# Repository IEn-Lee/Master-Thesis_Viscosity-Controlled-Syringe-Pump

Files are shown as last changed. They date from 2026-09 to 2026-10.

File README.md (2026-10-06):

# Viscosity-Controlled Syringe Pump for Precise Filling of a Urological Implant with High-Viscosity Oils

**Master's Thesis — I-En Lee**  
M.Sc. Computational Engineering  
Friedrich-Alexander-Universität Erlangen-Nürnberg (FAU)  
Institute for Factory Automation and Production Systems (FAPS)  
2026

**Thesis grade: 1.0 (highest possible grade in the German grading system)**  
**Recognition: Outstanding Master's Thesis** — [View certificate](https://github.com/IEn-Lee/Master-Thesis_Viscosity-Controlled-Syringe-Pump/blob/main/Certificate%20Outstanding%20Master's%20Thesis_Lee.pdf)<br>
**Full master's thesis:** The complete thesis is available as a PDF in this repository — [Full master's thesis](https://github.com/IEn-Lee/Master-Thesis_Viscosity-Controlled-Syringe-Pump/blob/main/Master_s%20Thesis.pdf). <br>
*(If GitHub fails to display the PDF preview, please download the file and open it locally)* <br>
<br>
> **RheoPilot | James Dyson Award 2026**  
> **[Explore the RheoPilot project on the James Dyson Award website](https://www.jamesdysonaward.org/en-US/2026/project/rheopilot)**

---

## Overview

This master's thesis developed **RheoPilot**, a **viscosity-controlled syringe pump for precise filling of a urological implant with high-viscosity oils**. The platform combines physical modeling, mechanical design, embedded control, sensor–actuator integration, a touchscreen interface, and experimental calibration in a working laboratory prototype.

The investigated fluids spanned approximately **1–60,000 mPa·s**, from water to high-viscosity silicone oils. The system was developed around **B. Braun Injekt Luer Lock Solo 2 mL syringes** and a narrow cannula, with a validation target of **1 mL delivery within ±1% volumetric deviation** under defined laboratory conditions.

<p align="center">
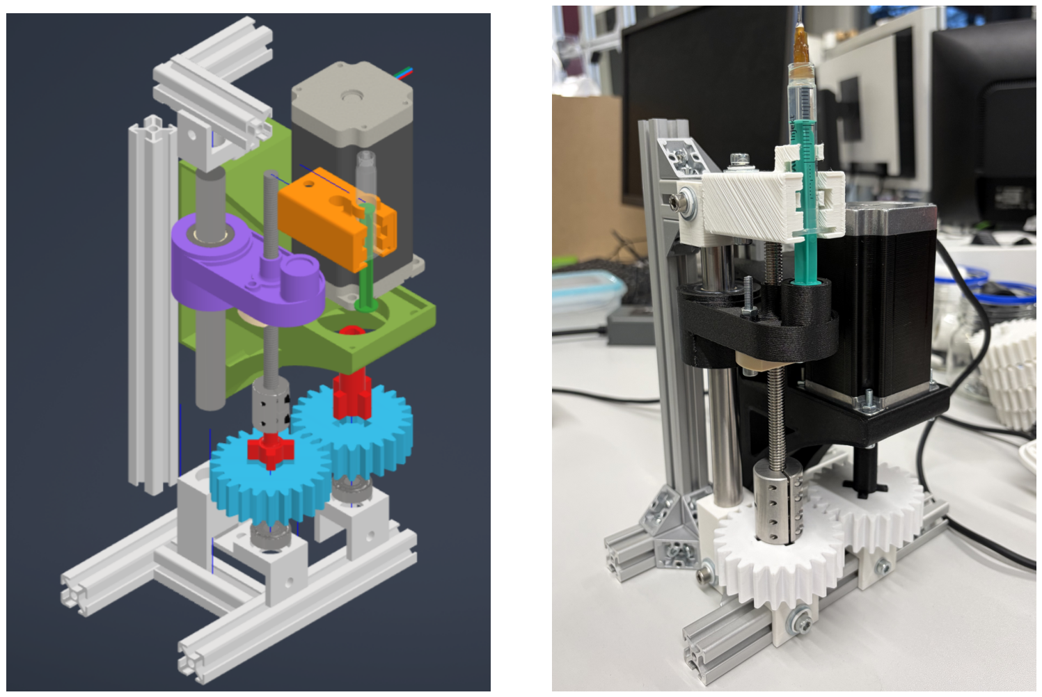
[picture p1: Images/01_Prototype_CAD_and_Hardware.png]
CAD installation reference beside the assembled syringe-pump prototype
  
</p>

*Figure 1. From CAD to a test-ready prototype. Left: installation reference. Right: the assembled syringe pump used for experimental evaluation. Source: original thesis Figure 39.*

**Key results**

- **Calibrated conditions:** maximum absolute volumetric deviation of **0.62%** across the reported trials at 1, 5,000, 30,000, and 60,000 mPa·s.
- **Intermediate validation:** at a nominal **40,000 mPa·s**, which was not a calibration point, **all five trials met the ±1% tolerance** using interpolated parameters without additional manual retuning.
- **Validation accuracy:** maximum absolute deviation of **0.93%** and mean absolute deviation of **0.72%** at that intermediate condition.
- **Post-extrusion handling:** retracting the plunger-contact interface enabled a standardized **3-minute post-release waiting interval** for the oil-based tests.

## Why This Research Was Needed

RheoPilot originated from a specific medical-device research problem: filling an internal component of an intraurethral implant with high-viscosity oil through a narrow cannula. This task requires a combination of accurate small-volume delivery, repeatable syringe positioning, manageable mechanical loading, and a practical laboratory workflow.

**Accurate plunger positioning alone does not guarantee accurate delivery at the outlet.** Under high-viscosity loading, syringe compliance, friction, structural deformation, and delayed outflow can change the relationship between commanded motion and delivered volume. In the thesis experiments, the uncompensated setting produced a mean absolute volumetric deviation of **30.31% at 60,000 mPa·s**, despite relatively consistent repeated trials. This made application-specific compensation necessary.

The equipment-selection challenge was to combine syringe-based operation with viscosity-dependent process planning and experimental flexibility. The thesis identified the following gap between existing approaches and the intended filling workflow:

| Approach considered in the thesis | Relevant capability | Additional need for this application |
|---|---|---|
| Conventional syringe pumps | Programmable plunger motion using syringe geometry, volume, and flow settings. | Compensation for the specific syringe–cannula system under high-viscosity loading, including delayed release. |
| Industrial viscous-material dispensers | Specialized metering of viscous materials. | Integration with the specified disposable 2 mL syringe and small-cannula implant-filling procedure. |
| Manual or semi-automated filling | Flexible preparation and operator intervention. | More reproducible actuation and post-extrusion handling, with traceable process settings. |

*This comparison summarizes the application-specific assessment in thesis Section 3.2 and Table 1; it is not an exhaustive benchmark of all commercial products.*

The resulting research objective was to develop an integrated **actuator–structure–fluid platform** that connects volume and viscosity inputs to motion planning, calibrated compensation, operator guidance, and quantitative validation.

### Why a Small Outlet Matters

<p align="center">
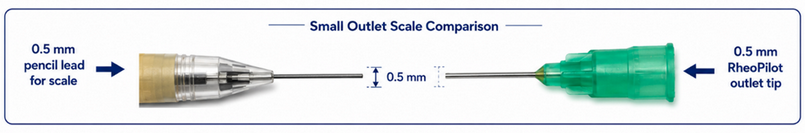
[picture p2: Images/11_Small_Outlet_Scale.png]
Visual scale comparison between a 0.5 mm mechanical-pencil lead and the RheoPilot cannula outlet
  
</p>

*Small-outlet scale comparison. The approximately 0.5 mm outlet scale is illustrated alongside a mechanical-pencil lead. This is a visual scale reference rather than a dimensional measurement.*

<p align="center">
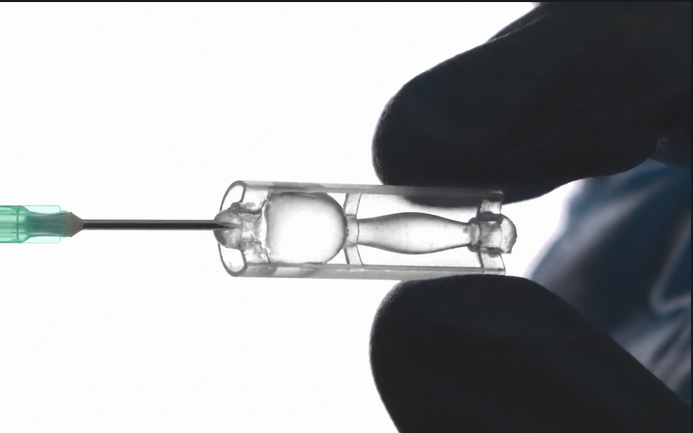
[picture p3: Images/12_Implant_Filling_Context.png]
Cannula positioned at the filling interface of a small transparent implant component held between gloved fingers
  
</p>

*Application context: cannula-based access to a small implant component. Image provided by the author; UroPro image credit: Alexander Preis, FAU FAPS.*

Small components can offer only a restricted filling interface. A narrow cannula provides localized access, but it also increases the resistance encountered by the fluid. Increasing the outlet size may therefore be incompatible with the component geometry or the required filling procedure.

For the idealized flow model used in this thesis, pressure loss scales with the inverse fourth power of the cannula radius. **Halving the radius increases the predicted pressure demand sixteenfold at the same viscosity, cannula length, and flow rate.** This makes a small outlet an important process constraint rather than merely a geometric detail.

RheoPilot addresses this constraint by relating viscosity and flow-path geometry to motion planning, then applying calibrated compensation for the actual syringe–cannula system. The objective is to deliver a defined volume through the required access point while accounting for mechanical loading and delayed material response.

## What Makes RheoPilot Different

**RheoPilot combines viscosity-dependent compensation with a compact, modular, standalone syringe-based workflow.** Its distinguishing feature is the combination of functions around the investigated filling task.

| Design feature | Practical value |
|---|---|
| **Viscosity-dependent motion planning and compensation** | Converts the filling task into motion settings that account for modeled loading and experimentally observed delivery deviations. |
| **Disposable-syringe compatibility** | Integrates the specified 2 mL syringe and Luer Lock cannula into a repeatable filling setup. |
| **Guided standalone operation** | Routine operation starts from target volume and viscosity; the embedded controller handles calculations, interface guidance, and motor commands on the device. |
| **Modular, fabrication-oriented construction** | Standard components and replaceable printed parts support assembly, modification, and iterative development. |
| **Advanced configuration access** | Exposes relevant setup parameters for research, while routine users interact with a simpler interface. |
| **Defined post-extrusion release** | Includes contact-element retraction and a standardized waiting step to address the delayed response of high-viscosity oils. |

The [RheoPilot project page on the James Dyson Award website](https://www.jamesdysonaward.org/en-US/2026/project/rheopilot) estimates **prototype parts costs of approximately €300–450**. This is a parts estimate, not a commercial selling price or a like-for-like comparison with a complete supported dispensing system.

The design supports adaptation of the syringe holder and outlet arrangement. **Each changed configuration would require appropriate calibration and validation**; the performance results below apply to the tested setup.

Figures 1, 4, and 5 show the physical implementation and modular interfaces; Figures 7–9 illustrate guided operation; Figure 10 and the validation tables explain the compensation strategy and measured results.

## My Contributions

- Developed a fluid-mechanical model and used Python for numerical evaluation of viscosity-dependent operating constraints.
- Designed the syringe fixation, plunger-contact interface, guidance, actuator mounting, and transmission interfaces in CAD.
- Applied **DFM and DfAM considerations**, including assembly clearances, printed-part tolerances, modular interfaces, and replaceable components.
- Integrated stepper-motor actuation, motor-driver electronics, electrical monitoring, embedded C/C++ software, and a touchscreen interface.
- Implemented **model-based open-loop compensation** using calibrated motion parameters and monotonic interpolation.
- Fabricated and assembled the prototype, conducted gravimetric experiments, and evaluated an intermediate condition excluded from calibration.

## 1. System Architecture and Integration

<p align="center">
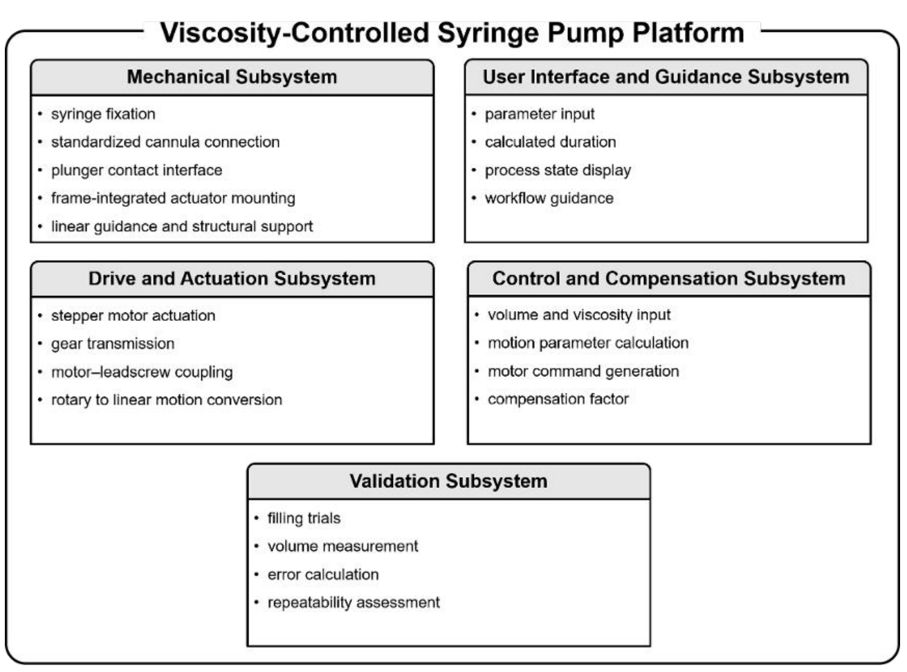
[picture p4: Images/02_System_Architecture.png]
Five functional subsystems: mechanics, drive and actuation, control and compensation, user interface and guidance, and validation
  
</p>

*Figure 2. Functional decomposition of the syringe-pump platform. Source: original thesis Figure 16.*

The architecture connects five engineering functions:

| Subsystem | Role in the filling process |
|---|---|
| Mechanical structure | Positions the syringe, supports the actuator, and guides the moving plunger-contact element. |
| Drive and actuation | Transfers motor rotation through the transmission and leadscrew into linear plunger displacement. |
| Control and compensation | Converts target volume and viscosity into executable, compensated motion commands. |
| User interface and guidance | Supports parameter entry, confirmation, process monitoring, and operator guidance. |
| Validation | Measures delivered volume and evaluates accuracy and repeatability under documented conditions. |

This structure made **system integration** central to the project: the model, hardware, firmware, interface, and measurement workflow had to operate consistently together.

## 2. Fluid-Mechanical Modeling and Motion Planning

<p align="center">
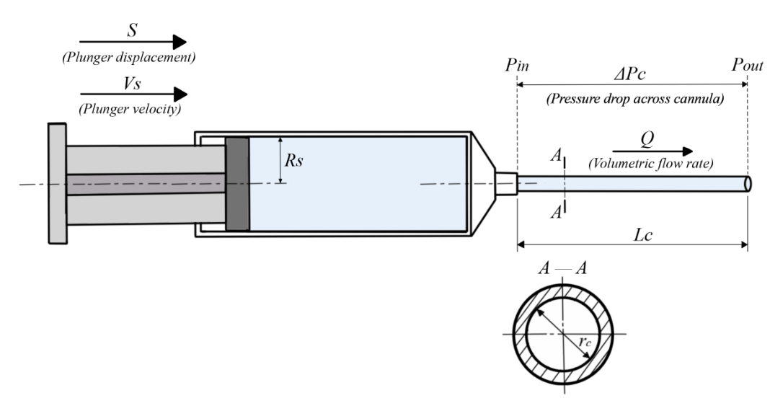
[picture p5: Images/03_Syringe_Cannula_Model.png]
Syringe–cannula model showing plunger displacement, plunger velocity, volumetric flow, and cannula pressure drop
  
</p>

*Figure 3. Simplified syringe–cannula model linking actuator motion to fluid flow and pressure demand. Source: original thesis Figure 5.*

The model relates plunger displacement and velocity to delivered displacement volume and volumetric flow. For idealized Newtonian flow through a cylindrical cannula, the Hagen–Poiseuille relation provides a first-order pressure-loss estimate:

$$
\Delta p_c = \frac{8\mu L_c Q}{\pi r_c^4}
$$

where $\mu$ is dynamic viscosity, $L_c$ is cannula length, $Q$ is volumetric flow rate, and $r_c$ is cannula inner radius.

**Figure 3 explains why actuator motion must account for the fluid path.** Increasing viscosity or flow rate increases the predicted pressure demand, while decreasing cannula radius has a particularly strong effect because of the fourth-power dependence. The pressure and force-transmission analysis informed feasible plunger motion and mechanical loading.

Python-based numerical evaluation supported parameter selection before hardware implementation. Defined acceleration and deceleration phases were used to avoid abrupt motion changes. The simplified model supported engineering decisions; it was not an exact predictor of transient pressure or delivered volume.

### Viscosity-Adaptive Motion Planning

<p align="center">
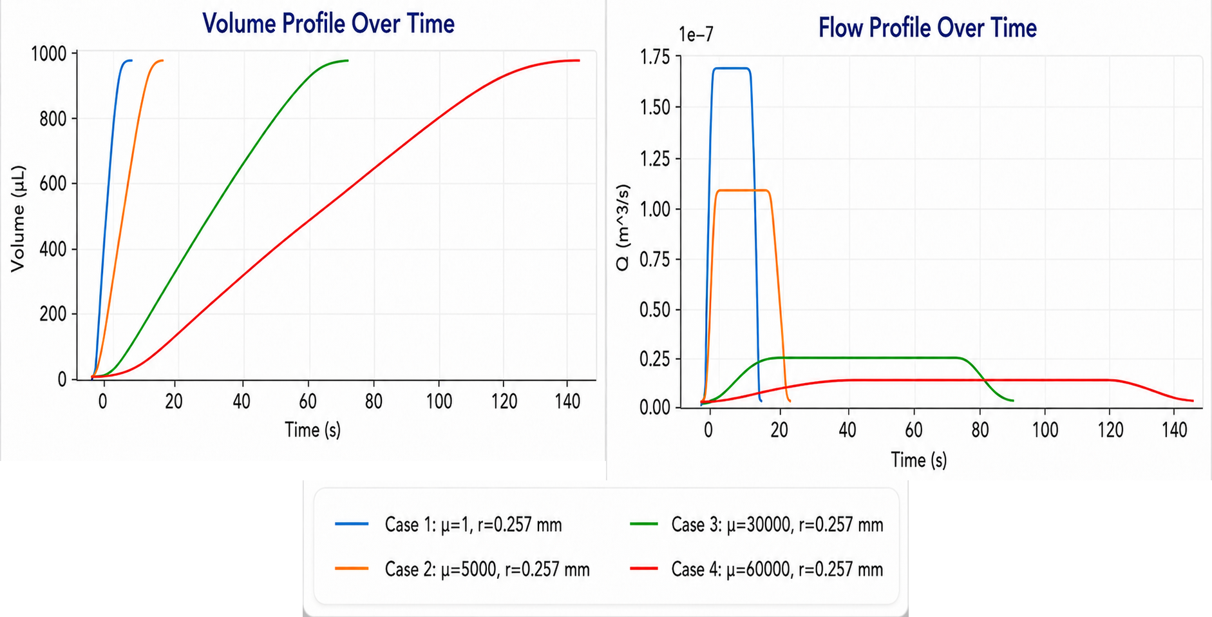
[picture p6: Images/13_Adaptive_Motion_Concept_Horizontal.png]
Conceptual volume and flow profiles illustrating different dispensing durations and flow rates for increasing viscosity
  
</p>

*Conceptual illustration supplied by the author: viscosity-dependent volume and flow profiles. The curves illustrate the planning principle; their numerical values are not experimental results or a quantitative model-validation plot.*

**The same target volume can require different motion profiles for different fluid conditions.** The left panel illustrates accumulated volume approaching a similar target over different durations. The right panel illustrates the corresponding flow-rate concept, including gradual increases and decreases rather than abrupt starts and stops.

The intended progression from blue and orange to green and red represents increasing viscosity. Within the modeled load constraints, a higher-viscosity fluid can require a lower planned flow rate and a longer dispensing time. For a fixed syringe cross-section, this corresponds to adapting plunger velocity and the acceleration and deceleration phases.

In RheoPilot, this adaptation occurs **before extrusion**, using the entered viscosity, target volume, configured geometry, and calibrated compensation settings. Here, “adaptive” means **parameter-dependent motion planning**. Direct outlet-flow or pressure measurements do not update the command during execution.

Motion-profile selection determines how the delivery is performed; the compensation map in Section 6 corrects the relationship between commanded displacement and measured delivered volume.

## 3. Mechanical Design, DFM, and DfAM

<p align="center">
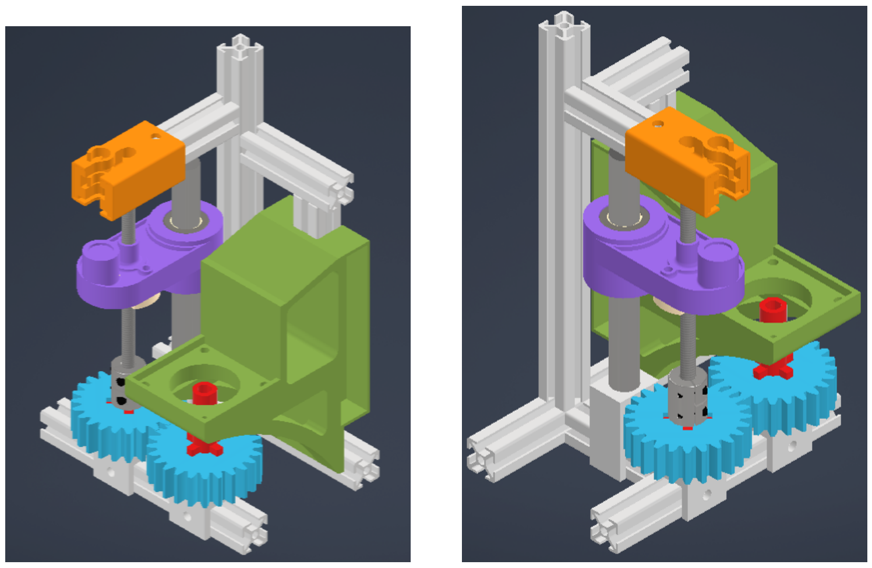
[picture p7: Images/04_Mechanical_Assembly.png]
Two CAD perspectives showing the syringe fixation, moving contact element, actuator support, and transmission
  
</p>

*Figure 4. Mechanical subsystem viewed from two perspectives. Source: original thesis Figure 17.*

The CAD assembly makes the force path and component interfaces visible. The **orange fixation** locates the syringe; the **purple moving element** contacts its plunger; the guide structure supports linear travel; and the **green frame section** supports the actuator. The gear and leadscrew arrangement converts motor rotation into plunger displacement.

The design priorities were axial alignment, repeatable syringe positioning, stable guidance, and practical assembly. Manufacturing and assembly considerations included:

- **Tolerance-aware contact:** clearance at the plunger-contact interface accommodates small alignment and dimensional deviations without rigidly locking the syringe plunger to the actuator.
- **Defined sliding interfaces:** a sliding bearing and stainless-steel guide rod reduce dependence on the surface quality of printed parts.
- **Modular construction:** replaceable printed components and defined interfaces support fabrication, maintenance, and iterative refinement.
- **Practical assembly:** leadscrew clearances, mounting features, and accessible component interfaces support repeatable installation.

<p align="center">
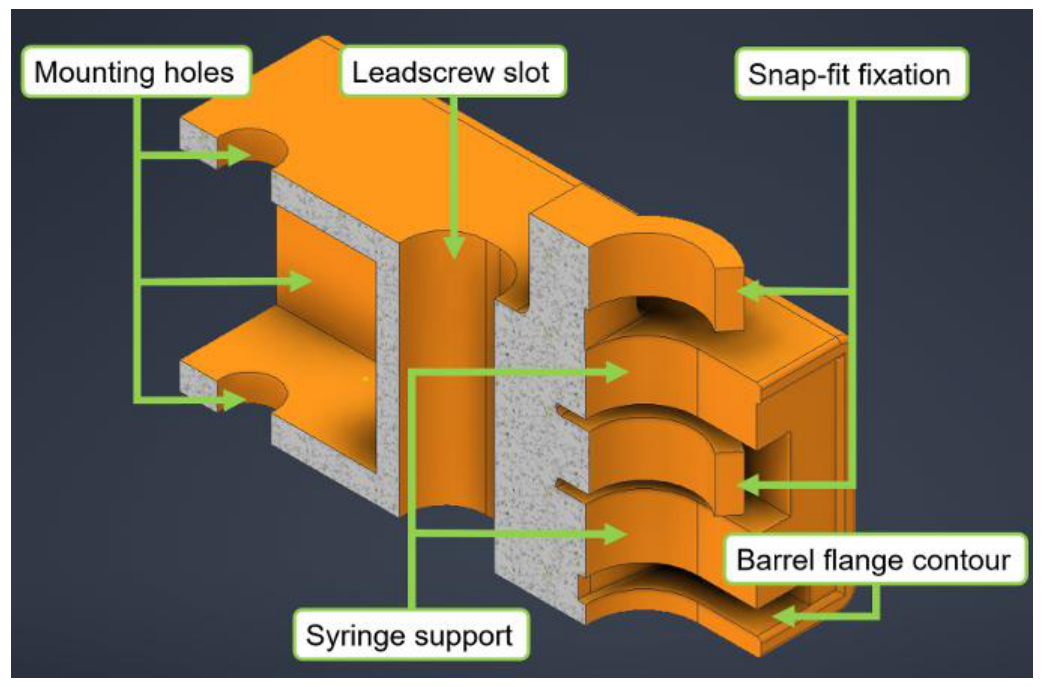
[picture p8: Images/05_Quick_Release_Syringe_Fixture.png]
Annotated syringe fixation with snap-fit, semi-enclosing support, barrel flange contour, leadscrew slot, and mounting holes
  
</p>

*Figure 5. Quick-release syringe fixation and locating features. Source: original thesis Figure 19.*

**The fixation in Figure 5 supports both repeatability and efficient syringe exchange.** A snap-fit enables insertion and removal, while the semi-enclosing support and barrel-flange contour resist unwanted displacement and tilting. The design avoids unnecessary over-constraint of the disposable syringe. The cannula connects directly through the syringe's standardized Luer Lock interface.

## 4. Actuation, Embedded Control, and Sensor Integration

The actuation system combines a **NEMA 23 stepper motor**, a **custom TMC5160-TA-based motor-driver board**, and leadscrew-driven linear motion. An **Arduino GIGA R1 WiFi** provides the main embedded controller, with embedded C/C++ software handling parameter processing, motion execution, driver communication, and user interaction.

<p align="center">
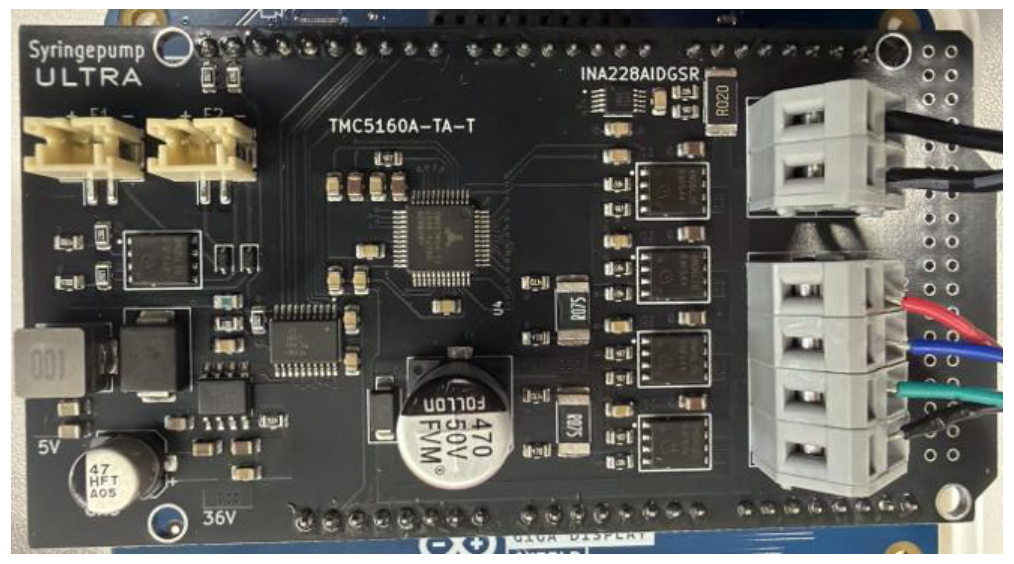
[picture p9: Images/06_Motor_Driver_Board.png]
Custom motor-driver board integrating the TMC5160-TA and electrical monitoring hardware
  
</p>

*Figure 6. Motor-driver electronics integrated into the syringe-pump platform. Source: original thesis Figure 25.*

**INA228-based electrical measurements** and motor-driver information support motor-side status monitoring. These functions connect sensing, actuation, and process visualization within the integrated system.

The extrusion strategy is **model-based open-loop control**: motion parameters are calculated and compensated before execution. The prototype does not use direct outlet-flow or pressure feedback to correct delivery during a run. Electrical monitoring and driver status therefore support process visibility without constituting closed-loop volumetric control.

## 5. Touchscreen Interface and Operator Workflow

The touchscreen interface separates routine filling tasks from advanced configuration. Routine operation focuses on viscosity and target volume; advanced access supports development, calibration, and manual motor functions.

<p align="center">
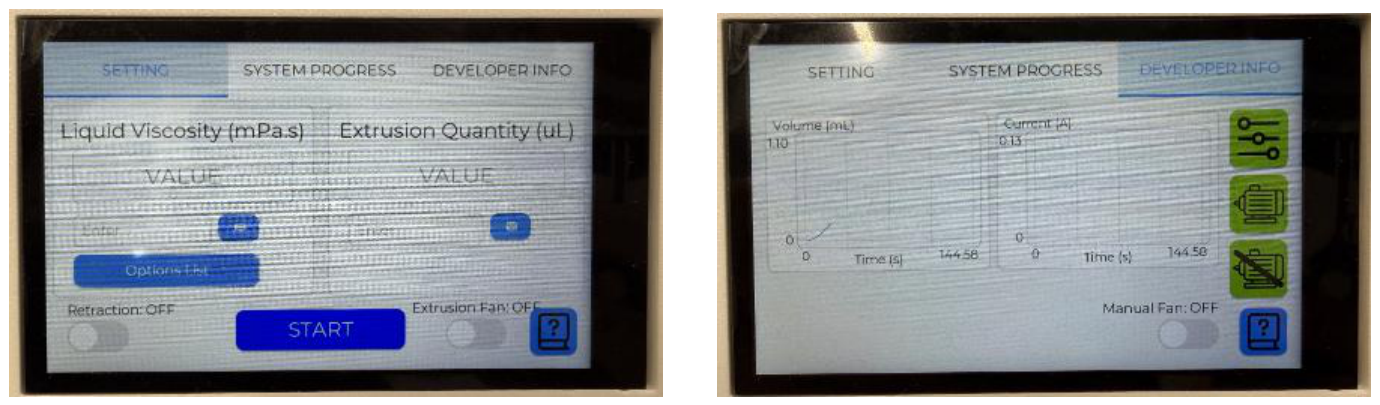
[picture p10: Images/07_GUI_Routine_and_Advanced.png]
Routine viscosity and volume input screen beside the advanced developer information screen
  
</p>

*Figure 7. Routine input screen on the left and advanced information access on the right. Source: original thesis Figure 33.*

**Figure 7 shows how the interface limits the complexity of normal operation** while preserving access to configuration parameters needed during research. Additional screens provide parameter customization, manual motor control, input warnings, and tab-specific help.

<p align="center">
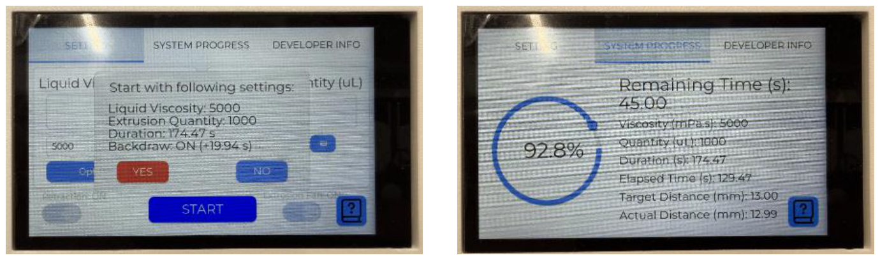
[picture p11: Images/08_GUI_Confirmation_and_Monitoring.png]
Pre-extrusion confirmation dialog beside the active process monitoring screen
  
</p>

*Figure 8. Pre-extrusion confirmation and process-state monitoring. Source: original thesis Figure 35.*

Before motion starts, the confirmation dialog summarizes the intended filling operation. During extrusion, the progress view displays process information such as elapsed and remaining duration, distance, and progress. These displays communicate the planned or reported motion state; they are not direct measurements of outlet volume.

<p align="center">
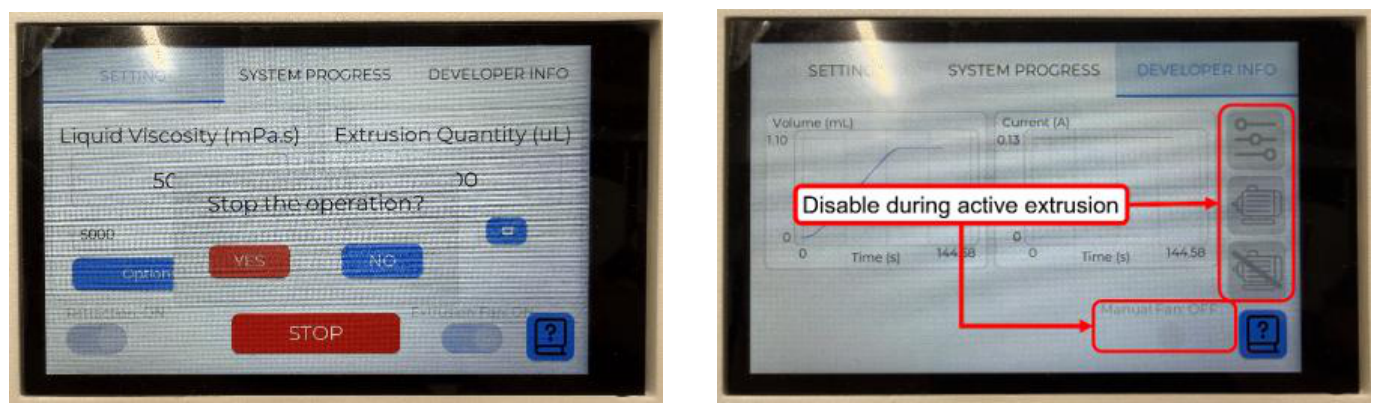
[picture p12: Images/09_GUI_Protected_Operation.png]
Stop confirmation dialog and advanced controls disabled during active extrusion
  
</p>

*Figure 9. Protected interaction during active extrusion. Source: original thesis Figure 36.*

A stop-confirmation dialog reduces accidental interruption, and selected advanced controls are disabled during active extrusion to prevent unintended changes. The interface was reviewed qualitatively against **Nielsen's 10 usability heuristics** as part of prototype design qualification.

## 6. Viscosity-Dependent Calibration and Compensation

Uncompensated experiments showed repeatable but viscosity-dependent under-delivery for the oils. This supported correcting a systematic process offset through an **effective motion scale**, which adjusts the relationship between commanded actuator motion and delivered volume.

Four conditions were used as calibration anchors: **1, 5,000, 30,000, and 60,000 mPa·s**. A monotonic interpolation map was constructed in the **logarithmic viscosity domain** to estimate compensation between these anchors.

<p align="center">
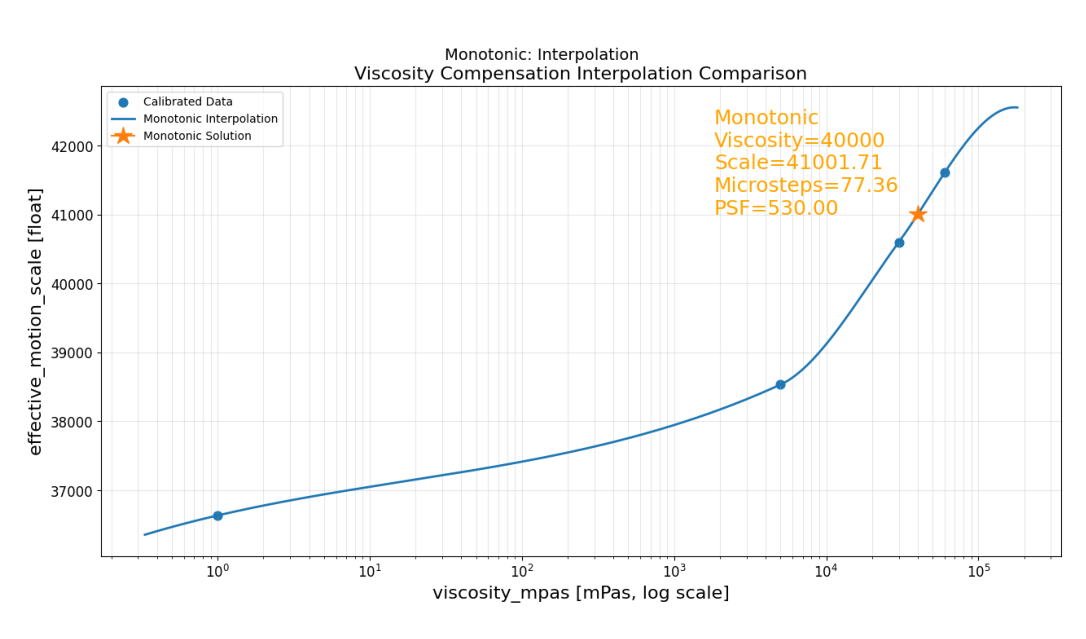
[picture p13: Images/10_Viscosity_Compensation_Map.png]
Monotonic compensation curve through four calibration anchors with an interpolated point at 40,000 mPa seconds
  
</p>

*Figure 10. Viscosity-dependent effective motion scale and the interpolated validation setting. Source: original thesis Figure 44.*

**How to read Figure 10:** the anchor points represent experimentally calibrated settings, and the curve estimates the effective motion scale between them. The highlighted **40,000 mPa·s** point gives a predicted scale of **41,001.71**. That value was obtained from interpolation, not from an additional manual calibration at the validation condition.

The effective motion scale is a firmware compensation quantity, not a directly measured fluid property. Its relationship with viscosity is specific to the investigated hardware and process conditions.

## 7. Experimental Validation and Quantitative Results

The evaluation followed a **DQ/IQ/OQ/PQ-inspired structure**, covering design requirements, installation readiness, operational behavior, and compensated performance.

### Measurement Conditions

- Nominal target volume: **1 mL**.
- Laboratory temperature: approximately **23 °C**.
- Fixed syringe type and cannula configuration; syringes used once.
- Gravimetric measurement using a **KERN PCD balance**.
- For water, measurement of the collected mass; for oils, measurement of syringe mass before and after extrusion.
- Mass-to-volume conversion using the specified fluid density.
- For oil-based trials, retraction of the plunger-contact interface followed by a standardized **3-minute post-release waiting interval**.

### Calibration Results

| Viscosity [mPa·s] | Baseline mean absolute deviation [%] | Calibrated mean absolute deviation [%] | Calibrated maximum absolute deviation [%] |
|---:|---:|---:|---:|
| 1 | 0.20 | 0.20 | 0.30 |
| 5,000 | 6.43 | 0.45 | 0.62 |
| 30,000 | 20.45 | 0.19 | 0.31 |
| 60,000 | 30.31 | 0.36 | 0.52 |

*Source: original thesis Tables 9 and 10; five reported trials per condition. These calibrated results were used for compensation-parameter selection.*

The baseline deviations increased with viscosity, while within-condition variation remained relatively small. Calibration reduced the reported absolute deviations, establishing the anchor settings used in the interpolation map.

### Validation at an Intermediate Viscosity

A nominal **40,000 mPa·s** condition, prepared by mixing the 30,000 and 60,000 mPa·s oils, was reserved for validation. The interpolated setting was applied **without additional manual retuning**.

| Validation metric | Result |
|---|---:|
| Repeated trials | 5 |
| Trials within ±1% volumetric deviation | 5 / 5 |
| Mean absolute volumetric deviation | 0.72% |
| Maximum absolute volumetric deviation | 0.93% |

*Source: original thesis Table 11.*

This result supports the feasibility of interpolation-based compensation at an intermediate condition within the tested range and setup.

### Why Post-Extrusion Release Matters

Stopping the motor does not immediately eliminate residual loading and delayed fluid response. Because the plunger is not rigidly coupled to the moving contact element, retracting that element releases the pushing contact and allows passive relaxation.

At **30,000 mPa·s**, a reference test without this release step still showed a mean absolute deviation of **8.53%** after **30 minutes**, with a **5.70-percentage-point** range between trials. The standard oil-based protocol incorporated release and a **3-minute** waiting interval.

This comparison demonstrates why post-motion handling belongs to the process design. It should not be interpreted as an isolated tenfold reduction in the complete filling-cycle duration.

## Future Development and Application Scenarios

RheoPilot provides a basis for extending a single filling operation into **programmable, time-scheduled fluid and material delivery**. A promising next step is to combine its viscosity-dependent dispensing method with the scheduling, sensor–actuator integration, touchscreen configuration, and fault-recovery experience developed in my [project thesis](https://github.com/IEn-Lee/Endourological-Test-Bench-Embedded-Control) on an automated biomedical test bench.

### Scheduled Dosing for Pharmaceutical and Biomedical Research

A future version could let users define **volume per dose, delivery interval, number of cycles, and dispensing duration**. The controller could then execute repeated dosing sequences and display the next scheduled event, completed cycles, and cumulative commanded volume.

Potential applications include reagent addition, repeated dosing in in-vitro experiments, and laboratory evaluation of drug-delivery schedules. A non-blocking scheduler would allow timing, user interaction, and process monitoring to operate together. Any extension to patient-facing drug delivery would require dedicated safety engineering and application-specific validation.

### Timed Material Feeding for Manufacturing Experiments

The platform could also be extended to deliver defined quantities of oils, silicone components, or other process materials at programmed times or in response to an external trigger.

Possible scenarios include repeated cavity filling, intermittent material addition, and synchronized feeding within a laboratory manufacturing setup. Material compatibility, the usable processing time of reactive materials, and the syringe–outlet configuration would guide the required hardware and control changes.

### Integration with Automated Test Platforms

Combining RheoPilot with a test-bench controller could coordinate dispensing with other experimental steps, such as pump operation, incubation periods, sensor acquisition, or sample preparation.

| Future capability | Relevant experience from the project thesis | Intended use |
|---|---|---|
| Scheduled delivery cycles | Non-blocking timing and automated cycle execution | Repeated doses or material additions at defined intervals. |
| Configurable experiment recipes | Touchscreen UI and parameter handling | User-defined volumes, intervals, and cycle counts. |
| Coordinated equipment operation | Sensor–actuator integration | Dispensing synchronized with other laboratory devices. |
| Monitored unattended operation | Communication-failure recovery and long-duration testing | Detecting faults and managing interruptions during repeated experiments. |

### Development Priorities

Further work would include repeated-dose accuracy testing, cumulative delivery assessment, refill handling, interruption and restart behavior, and timestamped event logging. Actual cumulative delivery would need measurement-based verification rather than relying only on the sum of commanded doses. Additional pressure, flow, or gravimetric sensing could support future delivery verification and feedback control.

**These are proposed extensions.** The current quantitative results apply to the tested single-delivery configuration; new fluids, geometries, schedules, and application scenarios would require their own calibration and validation.

## Outcome and Technical Skills

The work established an integrated workflow from **physical modeling and numerical evaluation to mechanical design, embedded implementation, prototype assembly, calibration, and experimental validation**.

Its main contribution is a working filling platform that combines viscosity-dependent motion planning with experimentally calibrated compensation and a defined post-extrusion procedure.

**Keywords:** Precision Fluid Handling · High-Viscosity Dispensing · Fluid-Mechanical Modeling · Mechanical Design · DFM · DfAM · Embedded C/C++ · System Integration · Sensor–Actuator Integration · Model-Based Open-Loop Compensation · Touchscreen UI · Experimental Validation

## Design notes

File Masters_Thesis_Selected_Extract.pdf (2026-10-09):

## Master’s Thesis — Selected Research Summary

Viscosity-Controlled Syringe Pump for Precise Filling of a Urological Implant with High-Viscosity Oils

Applicant | I-En Lee
Degree | M.Sc. Computational Engineering
Institution | Friedrich-Alexander-Universität Erlangen-Nürnberg (FAU)
Institute | Institute for Factory Automation and Production Systems (FAPS)
Supervisors | Prof. Dr. rer. nat. Jens Fürst; Alexander Preis, M.Sc.
Submission | 30 June 2026
Thesis grade | 1.0 (best possible grade)
Full thesis | View full thesis on GitHub (https://github.com/IEn-Lee/Master-Thesis_Viscosity-Controlled-Syringe-Pump/blob/main/Master_s%20Thesis.pdf)

Purpose of this document. This research summary presents the key aspects of my master’s thesis. The selected material highlights my experience in precision fluid handling, mechanical design, physical modeling, embedded control, prototype development, and quantitative experimental validation. These capabilities provide a foundation for further research in biomedical devices, advanced manufacturing, systems integration, and model-based engineering.

Research snapshot
The thesis addressed precise syringe-based delivery of fluids spanning approximately 1–60,000 mPa·s through
a narrow cannula. I developed an integrated platform combining fluid-mechanical modeling, mechanical design, stepper-motor actuation, embedded control, a graphical user interface, viscosity-dependent compensation, and gravimetric validation.
Calibration points at 1, 5,000, 30,000, and 60,000 mPa·s were used to construct a monotonic interpolation map. At an intermediate 40,000 mPa·s condition that was not used as a calibration point, all five validation trials remained within the defined ±1% volumetric tolerance, with a maximum absolute deviation of 0.93%.

All images reproduced in this document are taken directly from the original master’s thesis. Figure captions identify their corresponding source figure(s) in the submitted thesis. Explanatory text has been condensed and reorganized for PhD application purposes.

### 1. Research Problem and Engineering Objective

The application required repeatable filling of a small urological implant component using high-viscosity oil delivered through a narrow cannula. Under these conditions, commanded syringe-plunger displacement does not translate directly into delivered volume. Increasing viscosity and decreasing flow-path dimensions raise hydraulic resistance, while syringe compliance, plunger friction, structural deformation, and delayed material release can create additional deviations between actuator motion and outlet volume.
The engineering objective was therefore broader than designing a motorized syringe holder. The goal was to develop a process platform that could:
- relate target volume, fluid viscosity, syringe geometry, and cannula geometry to the filling process;
- provide mechanically stable and repeatable plunger actuation;
- convert process inputs into executable motion parameters;
- compensate for systematic viscosity-dependent deviations; and
- validate filling accuracy under controlled laboratory conditions.

The validation target used in the thesis was a nominal 1 mL delivery with a maximum permissible volumetric deviation of 1% under the defined experimental conditions.

### 2. Fluid-Mechanical Modeling and Numerical Evaluation

A simplified syringe–cannula model was used to describe how fluid properties and geometry influence the loading of the filling process. The model linked plunger displacement and velocity to volumetric flow and related the resulting cannula flow to pressure loss. For an idealized Newtonian flow in a cylindrical cannula, the first-order pressure estimate follows the Hagen–Poiseuille relation:

| ∆pc = 8µLcQ
| πr⁴ c ,

where µ is dynamic viscosity, Lc is cannula length, Q is volumetric flow rate, and rc is cannula inner radius.
The model was not treated as an exact transient pressure predictor. Instead, it provided a design-oriented description of the dominant dependencies that constrain actuator motion. Python was used for numerical evaluation of the fluid-mechanical relationships and viscosity-dependent system behavior before implementation of the physical control strategy.

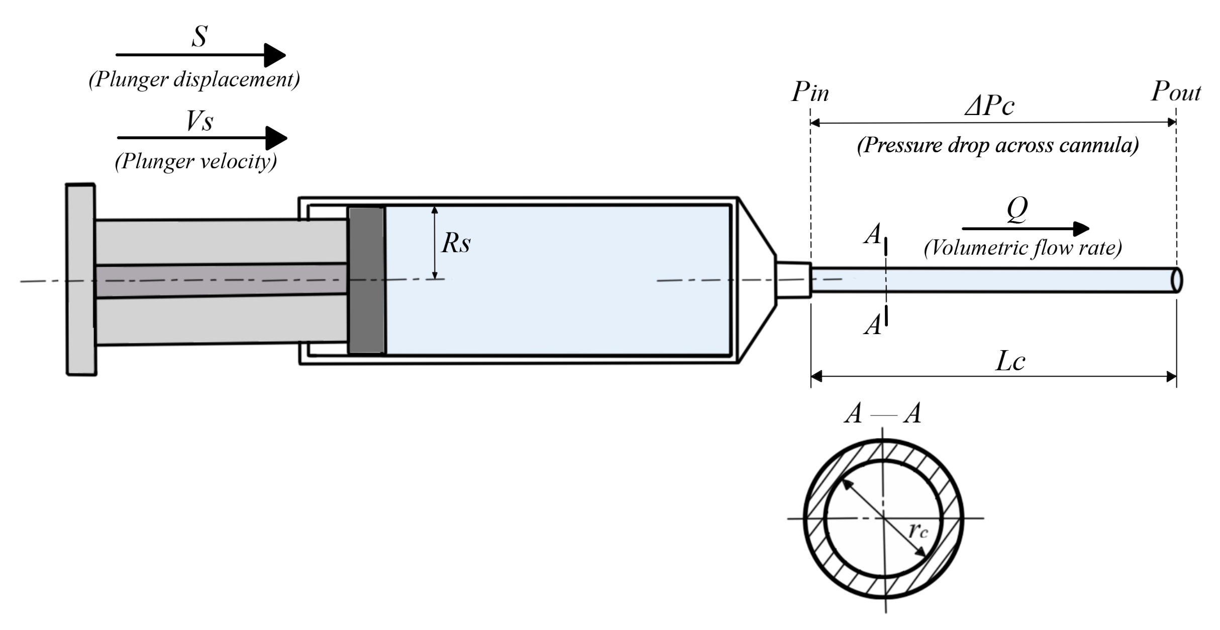
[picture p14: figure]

Figure 1 (original thesis Figure 5). Simplified syringe–cannula flow model used to describe the relationship between plunger motion, volumetric flow, cannula geometry, and pressure demand.

Two implications were particularly important for system design. First, viscosity changes pressure demand even when target volume and hardware geometry remain unchanged. Second, cannula radius has a strong nonlinear influence because it appears to the fourth power in the denominator.
For a fixed syringe and cannula geometry, increasing plunger velocity increases volumetric flow and therefore increases the estimated pressure demand. The actuator command consequently had to be treated as a fluid-constrained motion-planning problem, rather than only as a positioning task.

### 3. Mechanical Design and Manufacturability Considerations

The mechanical subsystem was developed around the disposable syringe, actuator, transmission, and guidance requirements. Particular attention was given to axial alignment of the actuator force with the syringe axis, repeatable syringe positioning, replaceable printed parts, practical syringe exchange, and interfaces that could accommodate the dimensional limitations of FDM-printed components.

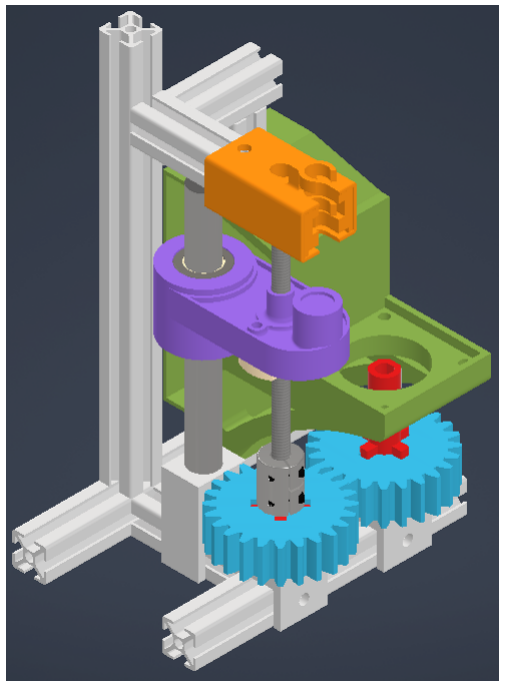
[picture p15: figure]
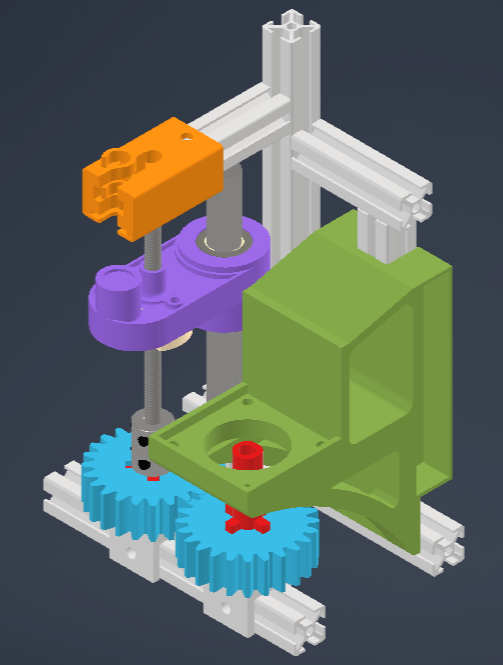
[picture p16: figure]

Figure 2 (original thesis Figure 17). Mechanical subsystem shown from two CAD perspectives, illustrating the structural frame, syringe fixation, plunger-contact interface, guidance elements, actuator mounting, and transmission system.

The syringe fixation used a quick-release concept and semi-enclosing support to improve repeatable positioning while avoiding unnecessary over-constraint. The plunger-contact interface incorporated clearance to accommodate small alignment and manufacturing deviations.
The design process considered how components would actually be produced and assembled. This included printed-part geometry, dimensional tolerances, clearance for assembly, modular interfaces, replaceable components, and practical assembly sequences. These considerations supported both manufacturability and repeatable laboratory assembly.

### 4. Prototype Realization, Actuation, and Embedded Control

The mechanical concept was developed into a test-ready electromechanical prototype through CAD refinement, component fabrication, assembly, actuator integration, and verification that the built hardware matched the intended operating concept.

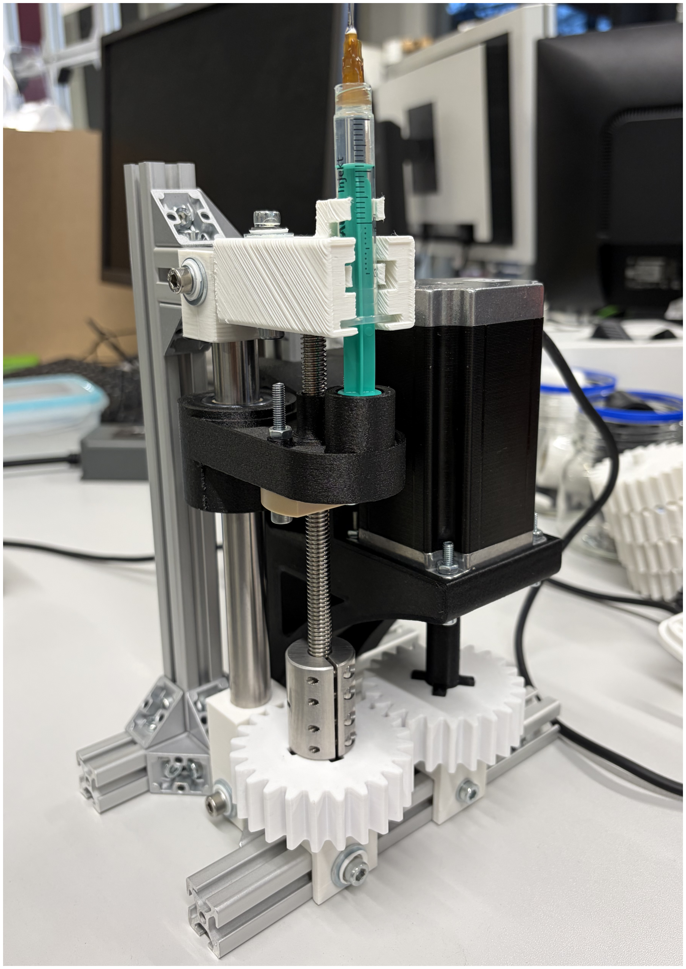
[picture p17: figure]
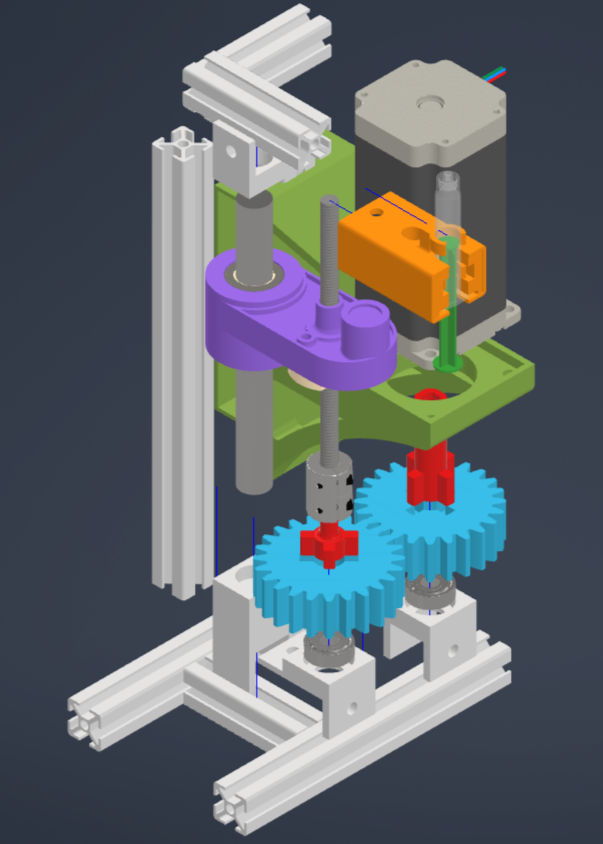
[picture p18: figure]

Figure 3 (from original thesis Figure 39). Left: CAD-based installation reference of the developed system. Right: assembled test-ready syringe-pump prototype used during experimental validation.

The final platform integrated a syringe fixture, leadscrew-based linear actuation, printed transmission components, supporting frame, and control electronics into a usable laboratory system.
The actuation system used a NEMA 23 stepper motor and a custom TMC5160-TA-based motor-driver board. An Arduino GIGA R1 WiFi served as the main embedded controller. Embedded C/C++ software handled parameter processing, motion execution, driver communication, process monitoring, and graphical user interaction. Motor-side status monitoring also incorporated INA228-based electrical measurements.
This created a complete model-to-hardware workflow: Python-based numerical evaluation → actuator and mechanical design → embedded C/C++ implementation → physical experimental testing.

### 5. Compensation Strategy and Viscosity-Dependent Interpolation

The final control approach was implemented as model-based open-loop extrusion control. Target volume and viscosity were converted into a distance-based actuator command, constrained by the modeled operating range and corrected using experimentally determined compensation parameters.
Direct pressure and outlet-flow feedback were not available in the prototype. Systematic deviations were therefore addressed before motion execution through calibration-based compensation and viscosity-dependent parameter estimation.
The effective motion scale was selected as the main compensation parameter. Calibration points were established at

1, 5,000, 30,000, and 60,000 mPa·s. Because the viscosity range spans several orders of magnitude, the compensation map was constructed in the logarithmic viscosity domain using monotonic interpolation.
The intermediate 40,000 mPa·s condition was reserved as a validation condition rather than used as another manually tuned calibration point.

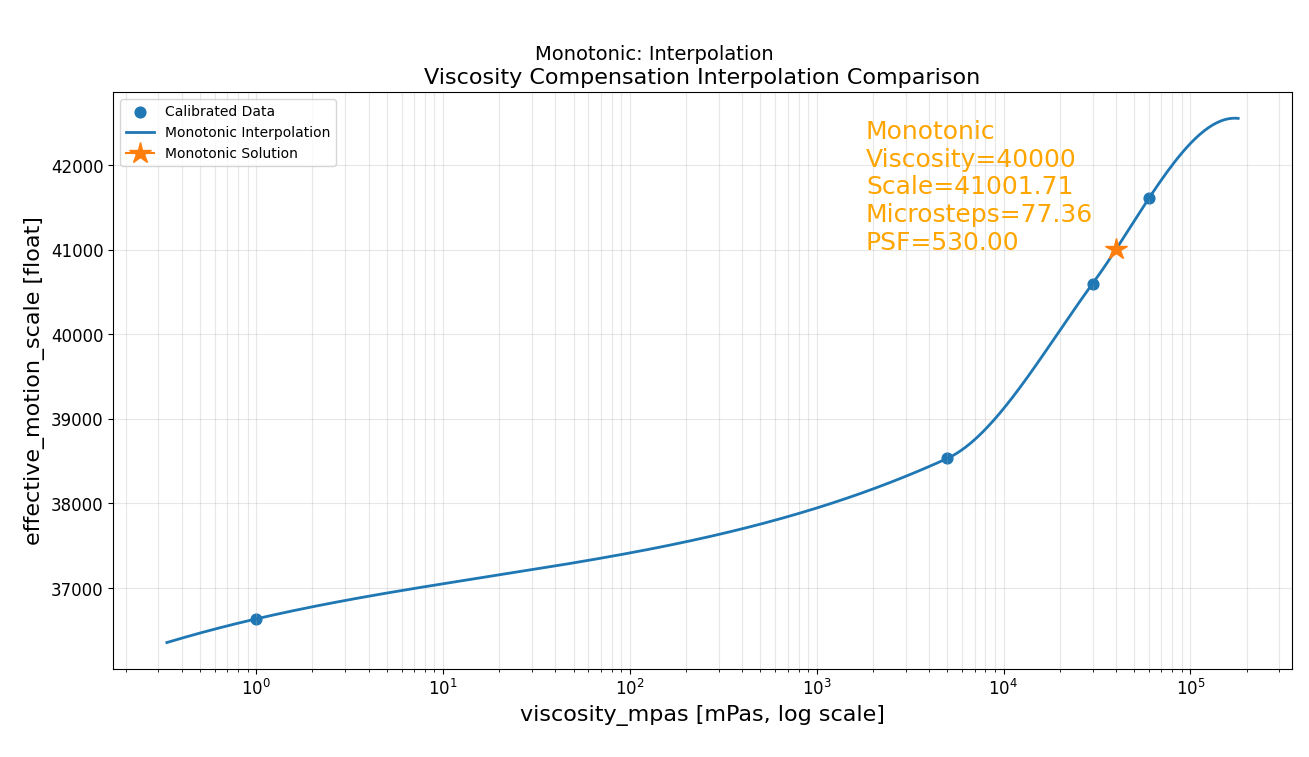
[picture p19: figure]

Figure 4 (original thesis Figure 44). Monotonic interpolation of the viscosity-dependent effective motion scale. The interpolation predicted an effective motion scale of 41,001.71 for the 40,000 mPa·s validation condition.

The interpolation complemented the physical model by compensating for systematic differences between ideal actuator displacement and actual delivered output under different viscosity conditions. Experimentally calibrated anchor points were therefore used to estimate a compensation parameter for intermediate viscosities within the tested range.

### 6. Experimental Validation and Key Result

The oil-based validation workflow used a fixed syringe–cannula configuration and controlled laboratory procedures to reduce avoidable trial-to-trial variation. The experiments were conducted at approximately 23◦C using the same
B. Braun Injekt Luer Lock Solo 2 mL syringe type and fixed cannula configuration. Syringes were used once, and the KERN PCD balance was tared before measurement.
For the high-viscosity oils, delivered volume was determined gravimetrically from the difference between the syringe mass before and after extrusion. The measured mass difference was converted to delivered volume using the supplier-specified specific gravity and compared with the nominal 1 mL target.
After extrusion, the plunger-contact interface was retracted and a standardized 3-min post-release waiting interval was applied before evaluation.
The 40,000 mPa·s condition had not been included among the four calibration anchor points. The interpolated compensation value was applied without additional manual retuning, and five repeated validation trials were performed.

Condensed from original thesis Table 11. Compensated extrusion performance at 40,000 mPa·s.

Trial | Syringe mass before [g] | Syringe mass after [g] | Volumetric deviation [%]
1 | 4.334 | 3.358 | 0.62
2 | 4.294 | 3.331 | -0.72
3 | 4.328 | 3.366 | 0.82
4 | 4.268 | 3.307 | -0.93
5 | 4.297 | 3.322 | 0.52
| | Mean absolute deviation | 0.72
Maximum absolute deviation | 0.93

All five trials remained within the defined ±1% volumetric tolerance. The maximum absolute deviation was 0.93%, and the mean absolute deviation was 0.72%.

Engineering significance
The result demonstrates a complete research workflow: physical modeling → numerical evaluation
→ device design → embedded implementation → experimental calibration → prediction at an intermediate condition not used for calibration → quantitative validation.

The experiments also showed that actuator displacement alone did not fully describe post-extrusion behavior. For high-viscosity oils, residual pressure and delayed outflow remained relevant after commanded motion ended. A passive-release step was therefore introduced by retracting the plunger-contact interface after extrusion.
This observation reinforced the need to treat the system as a coupled actuator–structure–fluid system rather than as a purely kinematic mechanism.

### 7. Transferable Research Capabilities

This thesis developed research capabilities that are directly relevant to biomedical device and systems research and advanced manufacturing, particularly where fluid behavior, mechanical design, actuation, fabrication, and experimental validation must be considered together:

- Fluid-mechanical reasoning: relating fluid properties and flow-path geometry to pressure demand, actuator loading, and device response.
- Python-based numerical modeling: evaluating fluid-dependent system behavior and candidate operating conditions before physical implementation.
- Model-to-hardware translation: converting physical and numerical analysis into actuator parameters, embedded control, and a working prototype.
- Electronic and embedded-system integration: integrating stepper-motor actuation, a custom TMC5160-TA-based driver, Arduino GIGA hardware, embedded C/C++, and process monitoring.
- Mechanical design and prototyping: CAD development, tolerance-aware interfaces, modular assembly, additive manufacturing, and iterative physical refinement.
- Quantitative experimental validation: defining measurable performance criteria, conducting repeated controlled trials, identifying systematic deviations, calibrating the system, and validating an intermediate condition not used for calibration.

These capabilities are directly transferable to biomedical device and systems research in which device geometry, mechanical behavior, fluid transport, fabrication, and experimentally measured performance must be considered together. This research experience provides a foundation for further development of biomedical devices and integrated engineering systems, while allowing me to continue expanding my expertise in advanced manufacturing, systems integration, and experimental validation.

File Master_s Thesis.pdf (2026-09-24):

## Viscosity-controlled syringe pump for precise filling of a urological implant with high-viscosity oils

Master Thesis in Computational Engineering

Friedrich-Alexander-Universitat Erlangen-N ¨urnberg ¨ Institute for Factory Automation and Production Systems Prof. Dr. Jens F ¨urst

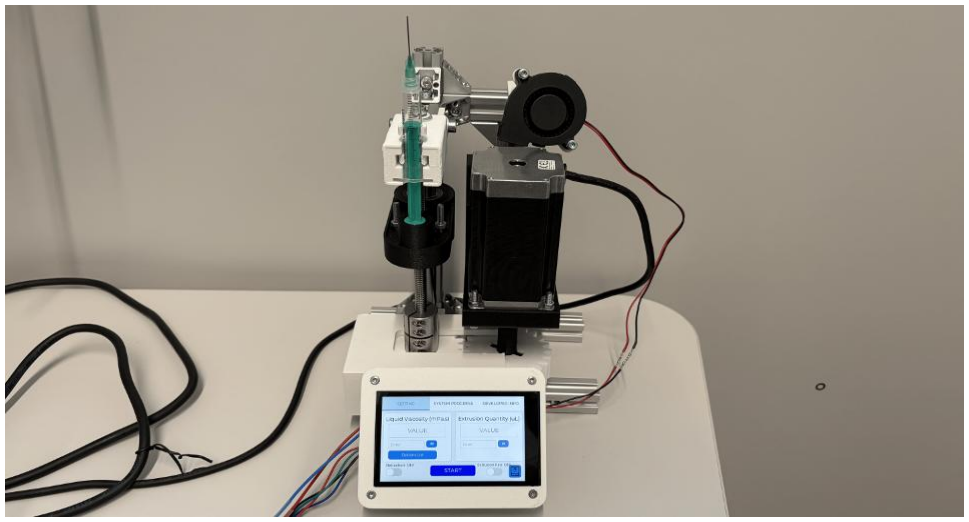
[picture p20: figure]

Author: | I-En Lee, 23365648
Supervisor(s): | Prof. Dr. Jens Furst ¨
| Dipl.-Ing. Alexander Preis
Submission date: | 30.6.2026
Processing time: | 6 months

# Declaration of Independent Work

I hereby declare that I, I-En Lee (23365648), have completed the submitted work independently and without unauthorized assistance from third parties, as well as without the use of undisclosed and, in particular, unauthorized aids. The work has not been submitted in the same or a similar form to any other examination authority and has not been accepted by any other examination authority as part of an examination.

The parts of the work that have been taken verbatim or in terms of meaning from other sources are clearly marked with citations of their origins (see citation guidelines). This also applies to drawings, sketches, visual representations, as well as sources from the internet.

When selecting artificial intelligence (AI) tools, compliance with data protection regulations (e.g., GDPR, HAWKI) must be ensured; tools without sufficient data protection guarantees should be avoided. No personal or confidential data may be entered into AI systems.

The author is responsible for independent execution of the work, for the accuracy of the information presented, as well as for the reflective, professionally appropriate, and ethically justifiable use of AI.

Violations of the above rules will be classified as deception or attempted deception and will result in the examination being graded as ”failed”.

I, I-En Lee, hereby declare the extent to which I have used AI, including tools such as Chat-GPT, Co-Pilot, HAWKI, DeepL Write, Grammarly or similar tools, in the preparation of this examination. I have used AI-supported tools as follows (please tick all applicable options):

□ Not at all – The work was created entirely without the use of AI tools.
□ For research and idea generation – AI was used to develop initial ideas, concepts or questions (must be documented in the work).
□ For creating outlines/structuring texts – AI was used as an aid to structure the work, and own adjustments were made.
□ For help with wording (e.g., improving sentence structure, style) – AI was used to improve style and readability, but not to generate the entire text.
□ For correcting grammar and spelling – AI was used for linguistic optimization, but not to change the content or generate text.
□ For translating texts – AI was used for translations, whereby all translated passages were revised and checked for accuracy.
□ For creating or optimizing graphics, diagrams, or visual representations – AI was used for visual representations that were interpreted and classified in the work.
□ For programming/code creation – AI was used to generate code, with all generated content being reviewed and commented on in a comprehensible manner.
□ For the creation of AI-supported summaries of scientific texts – AI tools were used to create summaries, the content of which was commented on in a comprehensible manner.
□ For other purposes, namely:

I confirm that I have provided complete and truthful information about all uses. I am aware that concealing or providing false information about the use of AI tools may be considered an attempt at deception and may have consequences under examination law.

Location, Date | Handwritten Signature

Contents | i

# Contents

3.3 Gap Between Ideal Displacement Control and Practical High-Viscosity Extrusion . 35

Contents | ii
4.2.3 Plunger Contact Interface and Force Transmission Path | 50
4.2.4 Frame-Integrated Actuator Mounting and Linear Guidance | 53
4.3 Drive and Actuation Method | 55
4.3.1 Drive Concept and Actuation Chain Overview | 55
4.3.2 Stepper Motor Actuation and Driver Integration | 56
4.3.3 Motor-Side Connector and Gear Transmission | 57
4.3.4 Gear-to-Leadscrew Interface and Rotary-to-Linear Motion Conversion . . . 59
4.3.5 Gear Rotation Stability and Bearing Support | 60
4.4 Control and Compensation Method | 61
4.4.1 Control Scope and Process Sequence | 62
4.4.2 Input Parameters, Target Distance, and Compensation Scaling | 63
4.4.3 Viscosity-Constrained Ramp Planning and TMC-Executable Command
Generation | 65
4.4.4 Motion Mode Management, Passive Release, and Waiting Time | 68
4.4.5 Monitoring Signals and Control Boundary | 69
4.5 User Interface and Guidance Design Method | 70
4.5.1 Translation of Usability Heuristics into Interface Requirements | 70
4.5.2 Interface Functions and Workflow Guidance | 70
4.5.3 Usability Evaluation Based on Nielsen’s Heuristics | 71
4.6 Experimental Validation Method | 73
4.6.1 Validation Structure Based on DQ, IQ, OQ, and PQ | 73
4.6.2 Design and Installation Qualification | 74
4.6.3 Operational and Performance Qualification | 75
4.7 Chapter Summary | 76

### 5 Results and Evaluation | 77

5.1 Overview of the Qualification Results | 77
5.2 Design Qualification and Installation Qualification Results | 77
5.2.1 Design Qualification Results | 77
5.2.2 User Interface Design Qualification Based on Nielsen’s Usability Heuristics . 78
5.2.3 Installation Qualification Results | 83
5.3 Operational Qualification Results | 85
5.3.1 Motion Execution and Process Monitoring | 85
5.3.2 Repeatability and Baseline Deviation | 88
5.3.3 Compensation Parameter Selection and Viscosity-Dependent Interpolation . 91
5.4 Performance Qualification Results | 97
5.4.1 Compensated Extrusion Performance | 97
5.4.2 Post-Extrusion Passive Release and Waiting-Time Behavior | 98
5.5 Chapter Summary | 100

### 6 Discussion | 101

6.1 Interpretation of the Results | 101
6.2 Limitations of the Developed Platform | 102

### 7 Summary and Future Prospects | 104

7.1 Summary of the Thesis | 104

Contents | iii
7.2 Future Prospects | 105
Bibliography | 107

List of Figures | iv

# List of Figures

1 | Schematic representation of a conventional artificial urinary sphincter system . . . | 4
2 | Prototype of the mechanical intraurethral AUS | | 5
3 | Cross-sectional illustration of the mechanical intraurethral AUS | | 5
4 | Schematic representation of syringe-based extrusion of low- and high-viscosity me-
| dia. The axial movement of the plunger displaces the fluid inside the syringe barrel
and forces it through the connected cannula. The figure was created by the author. . 12
5 | Simplified syringe–cannula flow model used for the fluid-mechanical description of
| the filling process. The plunger displacement generates a volumetric flow rate Q,
| while the cannula geometry, defined by the inner radius rc and length Lc , deter- mines the pressure drop ∆pc across the cannula. The figure was created by the
author | 14
6 | Calculated pressure drop as a function of the cannula inner radius for selected
| viscosity values. The vertical reference lines indicate the inner radii of the standard
| cannulas considered in this work. The strong increase in pressure drop at smaller
| radii results from the fourth-power dependence of the Hagen–Poiseuille equation.
The figure was calculated and created by the author | 15
7 | Calculated pressure drop as a function of dynamic viscosity for the 21G cannula
| used in this work with an inner radius of rc = 0.257 mm. The cannula length and
| volumetric flow rate are kept constant, while the viscosity is varied from water-like
| reference conditions to high-viscosity oil. The figure was calculated and created by
the author | 16
8 | Pressure-to-force transmission on the syringe plunger. The pressure difference re-
| quired for cannula-based extrusion acts on the effective syringe cross-sectional area As and results in the pressure-induced axial force component Fp . The figure
was created by the author | 17
9 | Buckling boundary conditions and corresponding effective buckling lengths for dif-
| ferent column end constraints. The effective length factor K depends on whether
the column ends are pinned, fixed, free, or partially constrained. Reproduced from [23].19
10 | Influence of the assumed plunger boundary condition on the maximum allowable
| volumetric flow rate as a function of dynamic viscosity. The figure was calculated
and created by the author | 21
11 | B. Braun Injekt Luer Lock Solo 2 mL disposable syringe used as the application-
| specific fluid container and mechanical interface in the investigated filling process.
The figure was created by the author | 30
12 | Commercial B. Braun Perfusor Space syringe pump as an example of a stan-
| dard medical syringe-based infusion and dispensing system. Reproduced from
B. Braun [28] | 32
13 | Preeflow eco-PEN XS 180 high-viscosity precision dispensing system as an exam-
| ple of an industrial viscous-material dispensing approach. Reproduced from Vis-
coTec/preeflow [29] | 33
14 Atlas Copco piston dispensing system as an example of industrial metering tech-
nology for viscous materials. Reproduced from Atlas Copco [30] | 34

List of Figures | v
15 | Nordson EFD UltimusPlus dispensing system as an example of a semi-automated
| dispensing approach for controlled fluid delivery. Reproduced from Nordson EFD [31].34
16 | Functional subsystem structure of the viscosity-controlled syringe pump platform
| used to organize the development method in Chapter 4. The figure was created by
| the author | 45
17 | CAD overview of the mechanical subsystem from two 45◦ perspectives, with colors
| used to distinguish different components of the system. The figure was created by
| the author | 47
18 | Complete CAD view of the syringe fixation. The figure was created by the author.. . 48
19 | Annotated section view of the syringe fixation showing the snap-fit fixation, semi-
| enclosing syringe support, barrel flange contour, leadscrew slot, and mounting
| holes for the aluminum profile. The figure was created by the author | 49
20 | Geometry overview of the plunger contact interface with the main functional re-
| gions. The figure was created by the author | 51
21 | Assembly view of the plunger contact interface with the syringe plunger, leadscrew,
| stainless steel guide rod, sliding bearing, and trapezoidal flange nut. The figure was
| created by the author | 52
22 | Assembly view of the plunger contact interface showing the actuation input via the
| spur gear and the intended force transmission path toward the syringe plunger. The
| figure was created by the author | 53
23 | Partial assembly views of the frame-integrated actuator mounting showing the rel-
| ative position of the actuator mounting and aluminum profile frame elements. The
| figure was created by the author | 54
24 | The overview of the drive and actuation chain showing the motor end, motor-side
| connector, spur gear, leadscrew-side connector, coupling end, and leadscrew end.
| The figure was created by the author | 55
25 | Custom-designed motor driver board integrating the TMC5160-TA for stepper mo-
| tor actuation. The figure was created by the author | 56
26 | Controller and display hardware used for embedded process control and user in-
| teraction. The figure was created by the author | 57
27 | Geometry of the motor-side connector and schematic assembly with the motor.
| The figure was created by the author | 58
28 | CAD-based view of the motor-side connector and gear interface, with the motor
| shown transparently to illustrate the assembled relative position of the motor, con-
| nector, and gear. The figure was created by the author | 58
29 | Gear-to-leadscrew interface with the leadscrew-side connector and the coupling.
| The figure was created by the author | 59
30 | Exploded assembly view of the spur gear, leadscrew-side connector, coupling, and
| leadscrew. The figure was created by the author | 60
31 | Design and assembly concept of the gear-to-bearing connector used to support
| smooth and stable spur gear rotation. The figure was created by the author.. . . . 61
32 | Conceptual velocity–time profile illustrating the role of the TMC5160 ramp-
| generator parameters. The profile shows the relationship between startVelocity,
| firstVelocity, maxVelocity, stopVelocity, firstAcceleration, maxAcceleration, maxDe-
| celeration, and firstDeceleration. The figure was created by the author | 67
33 | Routine input and advanced interface structure. The figure was created by the author.79

List of Figures | vi
34 | Advanced parameter customization and motor-control access. The figure was cre-
| ated by the author | 79
35 | Pre-extrusion confirmation and process-state monitoring. The figure was created
| by the author | 80
36 | Protected interaction during active extrusion. The figure was created by the author. . 80
37 | Invalid parameter warnings for required process inputs. The figure was created by
| the author | 81
38 | Embedded help and tab-specific user documentation. The figure was created by
| the author | 81
39 | Installation qualification overview showing the CAD-based installation reference
| and the assembled test-ready prototype. The figure was created by the author.. . . 83
40 | KERN PCD balance used as the gravimetric measurement device for subsequent
| extrusion trials. The figure was created by the author | 84
41 | Syringe pump prototype and GUI monitoring interface during operational qualifica-
| tion testing. The figure was created by the author | 86
42 | Motor thermal observation and selected radial fan for optional cooling. The figure
| was created by the author | 87
43 | Installed 5 V radial fan mounted on the rear frame and angled toward the motor
| housing for localized cooling. The figure was created by the author | 87
44 | Monotonic interpolation of the viscosity-dependent effective motion scale based
| on the calibrated compensation points. The interpolation follows the compensation
| map defined in Section 4.4.2, Equation 4.5. For the nominal 40000 mPa⋅s validation
| liquid, the interpolation predicted an effective motion scale of 41001.71. The figure
| was created by the author | 95

List of Tables | vii

# List of Tables

1 | Simplified comparison of existing filling approaches relevant to the present filling task 36
2 | Consolidated requirements for the viscosity-controlled syringe pump platform . . . 42
3 | Translation of Nielsen’s 10 usability heuristics into interface design and evaluation
| criteria | 72
4 | Qualification-inspired validation structure used for the experimental validation method.74
5 | Design qualification results based on the consolidated requirement areas derived
| in Chapter 3 | 78
6 | User interface design qualification based on Jakob Nielsen’s 10 usability heuristics.. 82
7 | Installation qualification checklist before operational qualification testing | 85
8 | Operational qualification results for motion execution and process monitoring. . . . 88
9 | Baseline repeatability results before compensation | 90
10 | Calibrated extrusion results used for compensation parameter selection | 93
11 | Compensated extrusion performance at 40000 mPa⋅s using the interpolated effec-
| tive motion scale | 98
12 | Extrusion results at 30000 mPa⋅s without post-extrusion passive release and with
| 30 min waiting time | 99

1. Introduction and Objective | 1

# 1 Introduction and Objective

Stress urinary incontinence refers to the involuntary leakage of urine caused by a sudden increase in abdominal pressure (such as coughing, laughing, sneezing, or lifting heavy objects) [1] due to the pelvic floor muscles being unable to provide sufficient support. It is a common urological condition that can affect a patient’s quality of life and necessitate long-term medical care. Epidemiological studies indicate that urinary incontinence is highly prevalent among the global population, with stress urinary incontinence representing an important subtype, particularly in women [2, 3]. Although urinary incontinence is particularly prevalent among women, when the focus of research shifts to implantable urinary control systems, relevant clinical studies and applications have primarily focused on severe male non-neurogenic stress urinary incontinence. Consequently, the high prevalence among women underscores the overall clinical significance of this condition, while research into male artificial urinary sphincter (AUS) serves as the primary engineering context for the AUS system. Clinical guidelines regard urinary incontinence as part of lower urinary tract symptoms and emphasize that it may cause distress and embarrassment for patients, as well as imposing a certain degree of financial burden [4]. AUS systems are currently one of the key treatment options for severe stress urinary incontinence and are particularly commonly used in male non-neurogenic cases. However, their long-term use remains associated with clinical and technical challenges, including revision surgery, device malfunction, infection, urethral erosion, and urethral atrophy. In addition, conventional AUS architectures require multiple implanted components and manual operation by the patient. These factors have prompted researchers to focus on simplified implant designs [5, 6, 7, 8]. However, the simplification of implant structures does not imply that their fabrication processes are correspondingly straightforward. Therefore, from an engineering perspective, these novel implants still require stable and reproducible manufacturing and validation processes. In particular, when device functionality depends on precise internal filling, control of the filling process becomes a key factor influencing device consistency and verifiability.

The Chair of Factory Automation and Production Systems (FAPS) previously proposed a new concept for an intraurethral AUS, aimed at addressing some of these limitations using an autonomous mechanical closure principle [9]. In the implant variant discussed in this thesis, the central occlusion component contains an internal cavity, which must be filled with high-viscosity oil in a predetermined and repeatable manner. Because of the small implant dimensions, the filling medium must be delivered via a small cannula, which presents a demanding syringe-based extrusion problem. Within the viscosity range considered in this thesis, which reaches up to 60,000 mPa⋅s, this high-viscosity oil generates significant flow resistance and can lead to pressure build-up, delayed flow initiation, residual pressure release, and deviations between the commanded plunger displacement and the actual dispensed volume. Previous research on syringe-based infusion and drug delivery devices has shown that, due to the syringe-based delivery method, the delivery process may be affected by start-up delay, compliance, flow-rate dependency, response time, and accessory-related effects [10, 11]. In the present application, these effects are particularly relevant because the filling medium used has a viscosity far higher than that of typical infusion solutions and must be extruded through a geometrically constrained cannula interface.

Therefore, the aim of this thesis is to develop a viscosity-controlled syringe pump system for the precise filling of the central occlusion component in urological implants. The system shall

1. Introduction and Objective | 2

translate application-specific input parameters, particularly the target filling volume and the viscosity of the filling medium, into reproducible syringe actuation commands. Based on these parameters and compensation factors derived from experiments, suitable motion parameters and extrusion durations are derived for the controlled extrusion of high-viscosity oil. The work covers the mechanical design of the pump system, the development of embedded control and user-interface software implemented on an Arduino GIGA Display Shield platform, and the experimental validation of the system under laboratory conditions. In addition to generating accurate syringe extrusion motion, the system supports user interaction, parameter handling, and validation-oriented process execution. These requirements are relevant in the development of medical devices, as traceability, repeatability, documentation, and validation-oriented process control are core elements of quality-management-oriented development [12].

## 1.1 Overview of Stress Urinary Incontinence (SUI)

Stress urinary incontinence refers to the involuntary leakage of urine during physical effort or exertion [1]. From a functional perspective, stress urinary incontinence (SUI) occurs when intra-abdominal pressure and bladder pressure temporarily rise, and urethral closure resistance is insufficient to counteract this pressure. This imbalance is commonly attributed to urethral sphincter insufficiency, weakened pelvic floor support, or a combination of both mechanisms.

Two functional mechanisms are commonly considered when describing SUI: reduced urethral support (often discussed in relation to urethral hypermobility) and insufficient urethral closure function (often described as intrinsic sphincter deficiency) [4]. In many patients, both of these mechanisms may contribute to the development of symptoms. The condition is particularly common in women, and its prevalence increases with age [3, 2]. Common risk factors in female patients include pregnancy, childbirth, obesity, and a history of pelvic surgery [4]. In men, SUI is less common and is often associated with sphincter impairment after prostate surgery [5, 8].

Clinically, SUI can range from occasional leakage during intense physical activity to frequent leakage during routine movements. Depending on the severity of symptoms, this may limit the patient’s daily activities, exercise, and social participation [4]. Therefore, treatment options should be selected based on symptom severity, underlying functional impairment, and the expected benefit to the patient. Before considering surgical or device-based interventions, conservative treatments, such as pelvic floor muscle exercises and lifestyle modifications, are usually prioritized [4].

When conservative treatment does not provide adequate symptom control, surgical or device-based approaches may be considered. For female patients, common treatment options include sling procedures. On the other hand, artificial urinary sphincter systems are more commonly used in men with severe non-neurogenic SUI and in specific complex cases [4, 5, 8]. Although these treatment options offer significant clinical benefits, they may also be associated with surgical risks, device-related complications, and long-term maintenance requirements. These limitations have prompted researchers to explore alternative device concepts with the aim of improving ease of use, reducing invasiveness, and ensuring reliable functional performance. For such device concepts, reliable performance also depends on reproducible preparation processes, particularly when the device functionality relies on precise internal volume filling. Within this thesis, these clinical considerations are not addressed as medical research ques-

1. Introduction and Objective | 3

tions but are used to define the application context for a syringe-based high-viscosity filling process.

## 1.2 Limitations of Conventional Artificial Urinary Sphincters

The AUS system is the standard treatment option for severe stress urinary incontinence and is particularly suitable for men with non-neurogenic cases or post-prostatectomy cases. Despite their clinical value is significant, long-term studies and systematic literature reviews report relevant device-related limitations, including revision surgery, device malfunction, infection, urethral erosion, and urethral atrophy [5, 6, 7, 8]. From an engineering perspective, these complications are of critical importance, as long-term urinary control efficacy depends on the reliability of mechanical and hydraulic components, the integrity of pressure transmission, and the usability of the implanted control interface. Failure of the urethral cuff, control pump, pressure-regulating balloon, or connecting tubing can compromise pressure transmission and lead to recurrent incontinence or revision surgery [8, 7]. Infection, urethral erosion, and tissue-related complications further limit the device’s longevity and increase the burden of follow-up care and potential revision surgery.

Another limitation of the conventional AUS system is the requirement for manual operation. Conventional AUS systems rely on a control pump, which the patient must press to initiate voiding. Figure 1 illustrates the basic structure of such a system, including the urethral cuff, control pump, pressure-regulating balloon, and connecting tubing. The need for manual operation introduces an additional usability requirement, since the patient must be able to locate and operate the implanted pump. This may prove challenging for elderly patients or those with reduced manual dexterity. Therefore, this factor should be considered when evaluating the suitability of conventional AUS systems [8].

The multi-component architecture of conventional AUS systems also increases the complexity of the implantation procedure. The cuff, control pump, pressure-regulating balloon, and connecting tubing must be positioned and connected across different anatomical regions, which increases the structural and procedural complexity of the system. Furthermore, conventional AUS have been predominantly applied in male patients, whereas their use in female patients is generally limited to recurrent or complicated SUI. Since the literature reports risks of complications, mechanical failure, and device removal, careful consideration is required before their use in female patients [4]. These aspects restrict broader clinical applicability and motivate the investigation of device concepts with reduced spatial requirements, simplified actuation, and reliable functional performance.

Overall, conventional AUS systems remain associated with limitations in terms of long-term reliability, usability, and clinical applicability. These limitations motivate the development of alternative device concepts that reduce system complexity and avoid manual actuation. For fluid-filled implant concepts, however, simplified device architecture also introduces an engineering requirement for a controlled and reproducible preparation process. If the functional behavior of such a device depends on a precisely defined internal oil volume, the filling process becomes a critical preparation step and requires accurate syringe-based extrusion control.

1. Introduction and Objective | 4

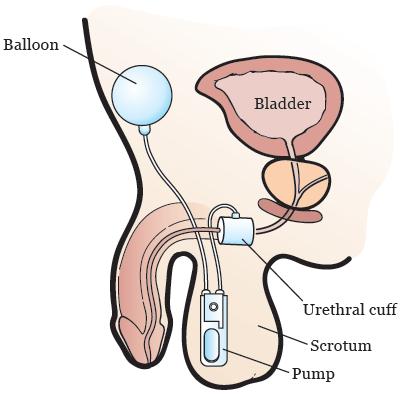
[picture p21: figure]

Figure 1: Schematic representation of a conventional artificial urinary sphincter system, consisting of a urethral cuff, a control pump, and a pressure-regulating balloon connected via tubing and implanted in different anatomical regions. Reproduced from Healthline [13].

## 1.3 Application Context: Mechanical Intraurethral Implant

The application context of the present thesis is a mechanical intraurethral AUS concept developed at the Chair of FAPS. The concept was proposed as an alternative to conventional AUS systems and aims to address limitations related to system complexity, manual handling, and sex-independent applicability [9]. In contrast to conventional patient-operated AUS architectures, the implant is based on an autonomous mechanical operating principle and does not require an external energy supply. Its function is controlled by pressure conditions within the lower urinary tract. Within this thesis, however, the implant concept is not investigated as a medical or implant-design research object. Instead, it defines the application-specific boundary conditions for a syringe-based high-viscosity filling process.

The basic closure mechanism consists of a pressurized closure balloon positioned inside a cylindrical intraurethral structure. The balloon acts as the occlusion element and blocks urine flow by pressing against the inner contour of the surrounding tube. It is connected through a throttle to a compensating reservoir, which enables pressure-dependent fluid exchange between the balloon and the reservoir. The interaction between these three components determines the opening and closing behavior of the implant [9]. Figure 2 illustrates the structure of the mechanical intraurethral AUS.

During normal conditions, the closure balloon remains sufficiently pressurized to seal the urethral passage, while short-term pressure peaks, such as those caused by coughing, are not intended to open the system. Opening occurs only when bladder pressure is increased over a longer period of time by active abdominal straining during micturition. Under this pressure state, fluid is displaced from the balloon through the throttle into the compensating reservoir. The resulting reduction in balloon volume decreases the sealing effect and allows urine flow. After the pressure condition changes, fluid can return from the compensating reservoir to the balloon, allowing the system to return to its closed state [9]. This pressure-dependent oper-

1. Introduction and Objective | 5

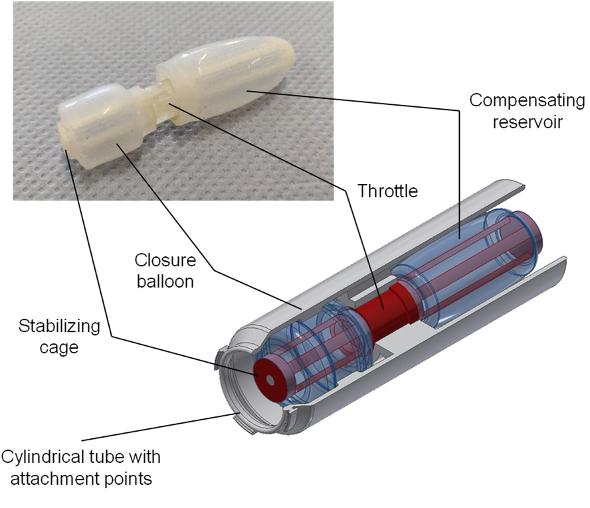
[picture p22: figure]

Figure 2: Prototype of the mechanical intraurethral AUS concept. The system consists of a closure balloon, a throttle, and a compensating reservoir for pressure-dependent regulation. Reproduced from Preis et al. [9].

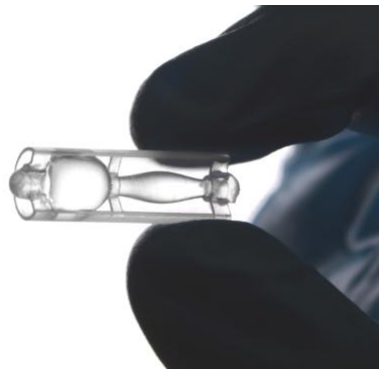
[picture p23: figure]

Figure 3: Cross-sectional illustration of the mechanical intraurethral AUS concept considered in this thesis. The closure balloon is positioned within a cylindrical intraurethral structure and connected through a throttle to a compensating reservoir for pressure-dependent regulation. Source: Chair of Factory Automation and Production Systems (FAPS), used with permission.

1. Introduction and Objective | 6

ating principle eliminates the need for manual actuation by the patient and therefore differs fundamentally from conventional artificial urinary sphincter systems with manually operated control pumps. In addition, the intraurethral arrangement reduces the number of spatially distributed components. This architecture is expected to reduce system complexity. However, its actual clinical applicability depends on the final device geometry, implantation procedure, and clinical evaluation.

For the present thesis, the implant is relevant primarily because its functional behavior depends on a defined filling state of the closure balloon. Before operation, the balloon must be filled with a defined liquid volume in order to establish the required internal pressure and sealing behavior. Deviations in filling volume or filling pressure can influence the opening and closing characteristics of the implant. The filling process is therefore not only an assembly step, but a functionally relevant preparation and validation process. The development and optimization of the implant itself are not the focus of this thesis. Instead, this work addresses the engineering task of developing a controlled syringe-based filling system for the implant’s occlusion component. Because the implant dimensions are small, the filling medium must be delivered through a small cannula. In combination with high-viscosity oil, this creates a high-resistance extrusion process in which pressure build-up, delayed flow response, and deviations between commanded plunger displacement and actual dispensed volume become relevant. This requirement forms the basis for the viscosity-controlled syringe pump investigated in the following chapters.

## 1.4 Challenges in Filling Implant Components over a Wide Viscosity Range

Filling the occlusion component of the implant is a functionally relevant step in device preparation, as the filling state affects the internal pressure and mechanical response of the occlusion mechanism. In the previously proposed concept of a mechanical intraurethral AUS, the closure function is achieved via a fluid-filled closure balloon [9]. In the implant variant considered in this thesis, the corresponding occlusion component contains a defined internal oil volume. Deviations in the filled volume may alter the pressure state and affect the opening and closing characteristics of the implant. The filling process is therefore not only an assembly step, but also a preparation and validation relevant process that must be controlled with sufficient accuracy and repeatability.

A central challenge lies in the fact that the filling system must handle a wide viscosity range. In this study, water with a viscosity of approximately 1 mPa⋅s was used as a low-viscosity validation boundary, while the viscosity of the application-relevant oils reaches up to 60,000 mPa⋅s. This viscosity range leads to substantially differences process conditions during syringe-based extrusion. While low-viscosity media can usually be displaced with comparatively low pressure, high-viscosity media require a larger pressure build-up to initiate and maintain flow. This behavior is consistent with the expected hydraulic resistance generated by pressure-driven flow through a narrow channel. According to the Hagen–Poiseuille relation, the required pressure drop increases with viscosity, volumetric flow-rate, and channel length, and decreases strongly with the fourth power of the channel radius [14]. Although the actual filling process may deviate from an ideal rigid circular tube, this relation illustrates the strong sensitivity of the process to the cannula radius. In this application, this effect is particularly relevant because the small

1. Introduction and Objective | 7

implant dimensions require the filling medium to be delivered through a small cannula. Depending on the material properties and process conditions, this may lead to delayed extrusion, increased flow resistance, residual pressure release, and deviations between the commanded actuator motion and the actual volume delivered.

The filling result is not determined by viscosity alone, but rather depends on the interaction between multiple process and system parameters. Temperature variations can change the effective viscosity of silicone oils, and previous work has modeled silicone-oil viscosity as a function of temperature and shear rate under application-specific flow conditions [15]. The geometry of the syringe defines the relationship between plunger displacement and theoretical volume output, while the syringe material, plunger seal, and connector design influence the mechanical boundary conditions of the filling path. In this thesis, the filling platform is based on a standardized disposable B. Braun Injekt Luer Lock Solo syringe, which provides a Luer Lock connection and a fixed syringe format for the mechanical interface [16]. The conversion between actuator motion and theoretical volume output is derived from the syringe-specific plunger displacement relationship determined for the selected syringe geometry. In addition, plunger friction, sealing behavior, and the mechanical compliance of the syringe and the connected filling path can influence pressure build-up and flow response. These effects are particularly relevant under high-resistance conditions, where part of the actuator movement may first contribute to elastic deformation or pressure generation before a steady-state material flow is established.

A further difficulty is the transfer of a desired filling volume into appropriate actuator commands. In an ideal rigid system, the dispensed volume could be calculated directly from the syringe cross-section and the plunger displacement. However, in practice, friction, compliance, start-up behavior, and viscosity-dependent flow resistance, can cause deviations from this ideal relationship. Similar effects have been reported in the literature for syringe-based drug delivery systems, where start-up delay, compliance, flow-rate dependency, response time, and accessory-related effects can influence the delivered volume or flow behavior [10, 11]. Consequently, without compensation for specific materials and systems, cannot reliably provide consistent results across the entire operating range, when using a fixed actuator speed or purely time-controlled strategy.

These challenges show that a suitable filling system must do more than generate linear actuator motion. It must support viscosity-dependent parameter calculation, controlled syringe actuation, and repeatable execution of a defined filling process. This forms the engineering basis for the development of a viscosity-controlled syringe pump system, which is designed to reproducibly deliver high-viscosity oils.

## 1.5 Requirements for an Integrated Viscosity-Controlled Filling System

The filling challenges described in the previous section translate into specific requirements for the design of the syringe pump system. A suitable filling system must not rely solely on manual operation or fixed time-based dispensing parameters. Instead, it must convert application-specific input parameters, including the target filling volume, fluid viscosity, and syringe configuration, into reproducible actuator commands. In this application, the viscosity ranges from 1 mPa s for water to 60,000 mPa s for high-viscosity oils. Under these conditions, if viscosity-

1. Introduction and Objective | 8

related flow resistance, start-up behavior, and system compliance are not considered, the same actuator setting may lead to different filling results.

For the implant component considered in this thesis, the enclosed fluid volume and the resulting pressure state represent preparation-relevant boundary conditions that influence the mechanical response of the occlusion component. Thus, the filling process should be accurate, predictable, and reproducible. Deviation in the filled volume will influence the preparation of the occlusion component and increase the workload required for further testing and validation. It is relevnat especially in small target volumes since even minor absolute deviations may represent a significant relative error. Therefore, the filling system must support defined process parameters and reproducible execution of filling operations under controlled laboratory conditions.

Additionally, the system must take into account mechanical restrictions of the syringe and the filling pathway. The syringe geometric, material properties, wall thickness, plunger sealing, and the design of connections all influence the required actuation force and the possible pressure that may arise during the extrusion process of the medium. It is especially important when extruding high-viscosity media, as the pressure necessary for extrusion can significantly increase. Since the current system cannot directly measure the fluid pressure, the control strategy must operate within empirically defined actuation limits, utilizing controlled motion parameters rather than closed-loop pressure regulation.

An integrated system architecture is required to combine actuation, parameter processing, user interaction, and process monitoring within a single platform. The control software must calculate the appropriate motion parameters based on the selected filling volume, viscosity, syringe configuration, and compensation factors determined through experimentation. At the same time, the user interface must provide a clear and reproducible workflow for entering process parameters, starting the filling sequence, and displaying relevant process information. Process monitoring, including commanded and actual motor states, current-related driver information, elapsed process time, and estimated remaining duration, can support the identification or later interpretation of abnormal process states and provide a basis for subsequent verification and qualification in a quality-management-oriented development environment [12].

The aim of this study is to develop a filling platform that integrates viscosity-dependent parameter calculation, controlled syringe actuation, a graphical user interface, and validation-oriented process monitoring. The system is designed to support reproducible filling operations under laboratory conditions and to provide a foundation for future process optimization, qualification-oriented testing, and early-stage medical device development workflows.

## 1.6 Research Question and Objectives

The main research question of this thesis is how to implement a viscosity-dependent syringe actuation on a desktop platform to enable accurate, reproducible, and configurable filling through a small cannula over a wide viscosity range. More specifically, this thesis investigates how to integrate viscosity-dependent parameter calculation, parameterizable syringe and process models, a graphical user interface, and process monitoring into a single filling platform. The aim is to provide a platform that supports controlled syringe actuation, defined filling sequences, and validation-oriented process execution under laboratory conditions.

To address this research question, the following research objectives have been established:

1. Introduction and Objective | 9
1. Design and implement a desktop syringe pump platform capable of controlled filling or extrusion through a small cannula.
2. Develop a viscosity-dependent parameterization and compensation strategy for adapting the extrusion process to media with viscosities between 1 mPa s and 60,000 mPa s.
3. Implement parameterizable syringe and process models that account for filling volume, fluid viscosity, syringe geometry, specified operating limits, and compensation factors.
4. Evaluate whether the filling accuracy whether the absolute volumetric deviation remains below 1% for a nominal filling volume of 1 mL under defined laboratory conditions.
5. Develop a graphical user interface with a simplified standard operating mode and an advanced mode with extended parameter access.
6. Develop monitoring functions capable of integrating motor-driver data and current-related driver information for process monitoring and diagnostic analysis.
7. Evaluate the filling process within a qualification-oriented framework, which includes Design Qualification (DQ), Installation Qualification (IQ), Operational Qualification (OQ) and Performance Qualification (PQ).

## 1.7 Structure of the thesis

this thesis is divided into seven chapters. Chapter 1 introduces the clinical background, the technical motivation, and the application context of the mechanical intraurethral implant. It also explains why a viscosity-controlled syringe-based filling system is required for the present application. The chapter then defines the research question and the main objectives of this thesis.

Chapter 2 provides the theoretical and technical background needed for the system development. The chapter discusses syringe-based dispensing, viscosity-dependent extrusion behavior, the relationship between syringe geometry and delivered volume, and the quality-management-related validation.

Chapter 3 derives the requirements for the syringe pump platform, which are based on the filling task defined in the previous section. The chapter identifies the mechanical, actuationrelated, user-interface, control, monitoring, and validation requirements that must be fulfilled by a viscosity-controlled filling system for the present application.

Chapter 4 describes how these requirements are implemented in the syringe pump platform. The chapter begins with the overall system architecture and then presents the mechanical design, including syringe fixation, the standardized cannula connection, the plunger contact interface, actuator mounting, and linear guidance. The drive and actuation subsystem is then described with respect to the stepper motor integration, gear transmission, the gear-to-leadscrew interface, and rotary-to-linear motion conversion. The remaining sections describe the user interface and guidance concept, the control and compensation method, and the experimental validation method based on Design Qualification, Installation Qualification, Operational Qualification, and Performance Qualification.

1. Introduction and Objective | 10

Chapter 5 presents the results and evaluation of the developed system. The chapter reports the Design Qualification and Installation Qualification results, including the evaluation of the mechanical design, user-interface design, and installation state. It then presents the Operational Qualification results, including motion execution, process monitoring, repeatability, baseline deviation, and viscosity-dependent compensation parameter selection. Finally, the Performance Qualification results evaluate the compensated extrusion performance and the post-extrusion passive release and waiting-time behavior.

Chapter 6 discusses the developed syringe pump system in relation to the research question and the derived requirements. The discussion evaluates the achieved filling accuracy, repeatability, viscosity-dependent compensation behavior, mechanical and control limitations, and the extent to which the system can support reproducible high-viscosity filling through a small cannula under laboratory conditions.

Chapter 7 summarizes the main findings of this thesis, evaluates the developed syringe pump system in relation to the defined objectives, and outlines remaining limitations and possible directions for future work. Particular attention is given to further optimization of the filling process.

2. Foundations and State of the Art | 11

# 2 Foundations and State of the Art

This chapter provides the theoretical and technical background for developing a viscosity-controlled syringe pump for filling through a small cannula. The focus is on the physical and system-related aspects that influence high-viscosity extrusion over a wide viscosity range. These include viscosity-dependent flow resistance, pressure build-up in the cannula, force transmission to the syringe plunger, mechanical limitations of the syringe system, and dynamic constraints of actuator motion.

The chapter begins with the principles of syringe-based filling and the analytical fluid-mechanical model used to describe pressure-driven flow through a cannula. Based on this model, the relationship between flow rate, viscosity, cannula geometry, and required pressure is formulated. The resulting pressure is then related to the required plunger force, allowing mechanical limitations such as plunger stability, allowable force, and acceleration-related dynamic loads to be considered. Subsequently, existing syringe pump systems and common extrusion control strategies are discussed with respect to their suitability for high-viscosity and viscosity-dependent filling processes. The role of embedded systems and graphical user interfaces in laboratory-scale devices is then addressed, followed by an overview of validation and quality-management-related considerations relevant to medical-device-oriented laboratory development. The chapter concludes by identifying the technological gaps that motivate the integrated filling system developed in this thesis.

## 2.1 Syringe-Based Filling of High-Viscosity Media

Syringe-based filling is used when small and defined liquid volumes must be delivered in a controlled manner. The basic principle relies on the axial movement of the syringe plunger, which forces the fluid from the syringe barrel through an outlet such as a cannula or filling needle. For low-viscosity fluids and ideally rigid components, this relationship can often be approximated from the syringe cross-section and the plunger displacement. However, for viscous media the delivered volume and the required extrusion force are also affected by the syringe geometry, plunger motion, outlet geometry, fluid viscosity, plunger friction, and downstream pressure conditions. Previous studies on syringe-based delivery and injectability report that viscosity, syringe and needle geometry, plunger friction, back pressure, and mechanical testing conditions can influence both the required extrusion force and the resulting delivery behavior [17, 18, 19]. Figure 4 illustrates the basic syringe-based extrusion principle considered in this thesis.

Under ideal geometric conditions, the theoretical dispensed volume can be related to the plunger displacement by

V = As

⋅ s = πR²
s
⋅ s | (2.1)

where V is the displaced volume, As
is the internal cross-sectional area of the syringe barrel, Rs

is the inner radius of the syringe barrel, and s is the axial plunger displacement. This equation provides a geometric relation between actuator motion and theoretical volume output. In practice, however, it remains an approximation. The actual dispensed volume can differ from

2. Foundations and State of the Art | 12

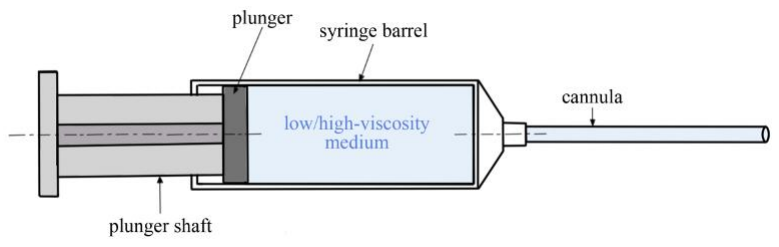
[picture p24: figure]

Figure 4: Schematic representation of syringe-based extrusion of low- and high-viscosity media. The axial movement of the plunger displaces the fluid inside the syringe barrel and forces it through the connected cannula. The figure was created by the author.

the calculated value because not all actuator motion is converted directly into fluid displacement.

For a target volume and an assumed constant volumetric flow rate, the required extrusion time can be estimated as

t =

V
Q

(2.2)

where t is the extrusion time and Q is the volumetric flow rate. For an ideal rigid syringe system, the flow rate can be related directly to the plunger velocity. In practice, this relation is limited by the mechanical limits of the syringe and actuator. For this reason, injectability studies usually consider not only the delivered volume, but also the force–displacement or force–time curves of the syringe-plunger system. These curves indicate the force required to extrude a material through a defined needle or cannula geometry [20, 21].

In the present work, the filling media range from 1 mPa s for water up to 60,000 mPa s for highly viscous oils. This range produces substantially different extrusion conditions. Low-viscosity fluids can be displaced with relatively low pressure, whereas highly viscous media require much higher pressure to initiate and maintain flow through the cannula. If viscosity-dependent flow resistance is not considered, the same actuator command may therefore produce different filling behavior.

The pressure demand of cannula-based extrusion can be estimated using an idealized pressure–flow relation for laminar flow through a cylindrical channel. The following section formulates this pressure–flow relation and links viscosity, cannula geometry, flow rate, and pressure demand. For the present application, this relationship is particularly relevant because the small implant dimensions require the filling medium to be delivered through a small cannula, making the outlet geometry a dominant factor for the required pressure and plunger force.

The ideal Hagen–Poiseuille relationship is useful for estimating the basic pressure–flow behavior, but real filling processes may deviate from this simplified model. First, the actual flow path may include connectors, transitions, or local restrictions that are not represented by an ideal cylindrical tube. Second, the effective viscosity of high-viscosity silicone oils may vary with temperature and, depending on the material and shear conditions, with local shear rate. Previous work on silicone-oil flow in viscous-damper applications has shown that temperature and shear-rate-dependent viscosity models can be relevant under application-specific flow condi-

2. Foundations and State of the Art | 13

tions [15]. In the present thesis, viscosity is treated as an input parameter for process calculation, while shear and temperature-dependent effects are considered as possible sources of deviation between ideal model behavior and practical filling performance.

In addition to viscosity-dependent pressure losses, high-viscosity filling processes can exhibit transient start-up effects. After the actuator begins to move, part of the motion may initially contribute to pressure build-up, elastic deformation of the syringe or connected filling path, and the overcoming of static friction before stable material flow is established. These transient and compliance-related effects are consistent with the non-ideal delivery behavior reported for syringe-based delivery systems [10, 11]. Under high-resistance conditions, this can create a delay between commanded plunger motion and actual fluid extrusion. The actual dispensed volume may therefore differ from the theoretical displacement volume.

Syringe-based filling of high-viscosity media therefore cannot be treated as a displacementonly process. The filling result depends on syringe geometry, cannula geometry, fluid viscosity, pressure build-up, friction, and transient start-up behavior. A fixed time-based or purely manual dispensing approach is therefore unlikely to provide reproducible filling over the full viscosity range considered in this thesis. The following sections use these dependencies to derive the fluid-mechanical and force-transmission models needed for viscosity-dependent actuator parameter selection.

## 2.2 Fluid Mechanical Model of Cannula-Based Extrusion

Since plunger displacement alone does not define the outlet behavior under high-resistance conditions, this section introduces the pressure–flow relation used to estimate the pressure required for cannula-based filling. In the simplified model used in this thesis, the narrow cannula is treated as the dominant hydraulic resistance of the filling path. The implant itself is not modeled in this section; its relevance lies in the small geometric constraints that require the filling medium to pass through a small cannula. As a result, the cannula radius, cannula length, volumetric flow rate, and fluid viscosity become the main parameters for estimating the pressure required to sustain flow. Figure 5 shows the simplified syringe–cannula flow model used in this thesis.

For an incompressible Newtonian fluid under steady, laminar, and fully developed flow conditions in a rigid cylindrical channel, the relationship between pressure drop and volumetric flow rate can be described by the Hagen–Poiseuille equation [14]:

Q =

πr

4
c∆pc
8µLc

(2.3)

where Q is the volumetric flow rate, rc

is the inner radius of the cannula, ∆pc is the pressure
drop across the cannula, µ is the dynamic viscosity of the filling medium, and Lc
is the effective
flow length of the cannula. In this thesis, Equation 2.3 is used as a first-order analytical model for estimating the pressure demand of cannula-based extrusion.

For process planning, Equation 2.3 can be rearranged to express the pressure drop required for a selected flow rate:

2. Foundations and State of the Art | 14

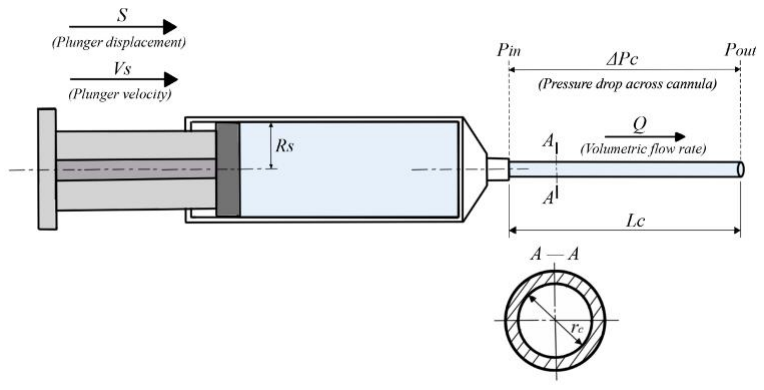
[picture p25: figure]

Figure 5: Simplified syringe–cannula flow model used for the fluid-mechanical description of the filling process. The plunger displacement generates a volumetric flow rate Q, while the cannula geometry, defined by the inner radius rc and length Lc
, determines the pressure drop ∆pc across the cannula. The figure was created by the author.

∆pc =

8µLcQ
πr⁴
c

(2.4)

In the present filling task, the equation is used primarily to identify the parameters that increase the pressure load on the syringe system. At a fixed cannula radius, higher viscosity, higher volumetric flow rate, and a longer effective cannula length all increase the required pressure. By contrast, the influence of the cannula radius is nonlinear because the radius appears to the fourth power in the denominator. A small reduction in the inner radius can therefore lead to a large increase in pressure demand. Similar dependencies between viscosity, needle or cannula geometry, flow rate, and required injection force have been described in syringe and injection-device studies [17, 18].

The sensitivity to cannula radius is relevant for the present system because the filling path is constrained by the small implant geometry. Figure 6 illustrates the calculated pressure drop as a function of the cannula inner radius for selected viscosity levels used in this work. The calculation illustrates the strong sensitivity of the pressure demand to the cannula radius under otherwise constant process conditions.

To separate the effect of viscosity from the geometric influence of the cannula, the cannula geometry and flow rate can be kept constant in the analytical calculation. Figure 7 shows the calculated pressure drop for the 21G cannula used in this work over the viscosity range considered in this thesis. With constant cannula radius, cannula length, and flow rate, Equation 2.4 predicts a linear increase in pressure drop with dynamic viscosity.

Together, Figures 6 and 7 show that a fixed target volume can require substantially different pressure levels depending on cannula geometry, extrusion duration, and fluid viscosity. These dependencies define the operating window in which the syringe pump must generate actuator motion without exceeding the mechanical limits of the syringe and plunger interface.

The volumetric flow rate can be related to the target filling volume and extrusion duration by

2. Foundations and State of the Art | 15

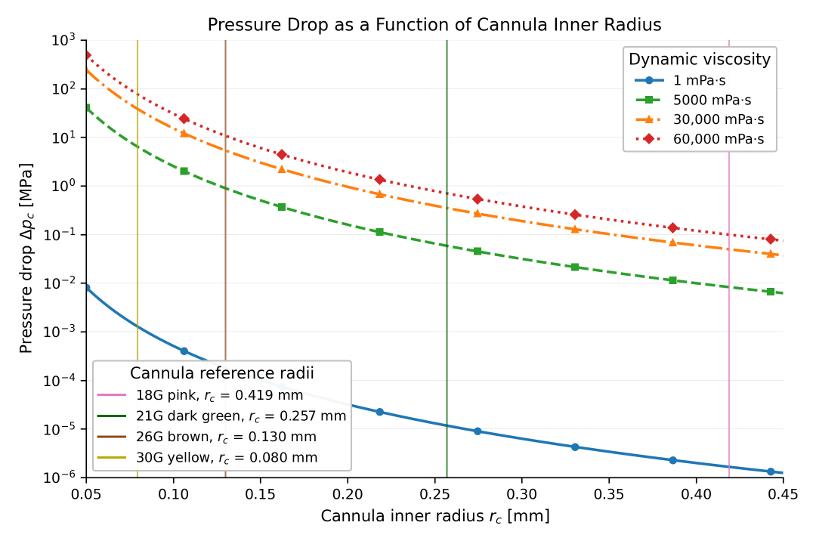
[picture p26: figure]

Figure 6: Calculated pressure drop as a function of the cannula inner radius for selected viscosity values. The vertical reference lines indicate the inner radii of the standard cannulas considered in this work. The strong increase in pressure drop at smaller radii results from the fourth-power dependence of the Hagen–Poiseuille equation. The figure was calculated and created by the author.

Q =

V
t

(2.5)

where V is the filling volume and t is the extrusion duration. Substituting Equation 2.5 into Equation 2.4 gives

∆pc =

8µLcV
πr⁴
c

t

(2.6)

For a given filling volume, extrusion duration affects not only process time but also the pressure load of the filling process. Reducing the extrusion time increases the required volumetric flow rate and, according to Equation 2.6, the pressure drop across the cannula. This is particularly important for highly viscous oils, where short extrusion times can lead to high plunger forces and may bring the syringe, the plunger contact interface, or the actuator system close to their mechanical operating limits.

The flow rate can also be written in terms of the plunger velocity. With the syringe barrel cross-section As = πR²
s

, the flow rate generated by the plunger motion is

Q = Asvs = πR²
svs
(2.7)

where Rs

is the inner radius of the syringe barrel and vs is the axial plunger velocity. Combining

2. Foundations and State of the Art | 16

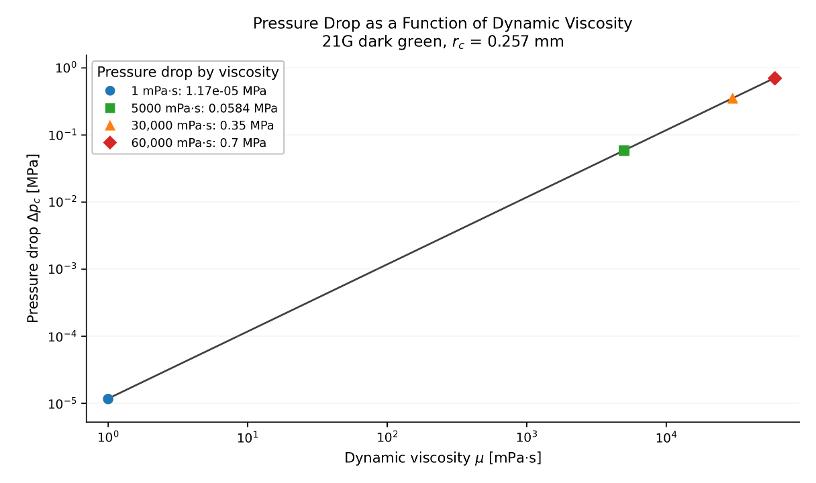
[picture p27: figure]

Figure 7: Calculated pressure drop as a function of dynamic viscosity for the 21G cannula used in this work with an inner radius of rc = 0.257 mm. The cannula length and volumetric flow rate are kept constant, while the viscosity is varied from water-like reference conditions to high-viscosity oil. The figure was calculated and created by the author.

Equation 2.7 with Equation 2.4 gives

∆pc =

8µLcR

2
svs
r

4
c

(2.8)

For a fixed syringe and cannula geometry, this equation shows that the pressure drop increases with plunger velocity and viscosity. The selected plunger velocity therefore acts as both a motion parameter and a process parameter, because it directly affects the pressure load of the filling path. In the present system, it must be chosen with respect to the viscosity of the filling medium and the cannula geometry.

The analytical model is used to estimate the magnitude and sensitivity of the pressure demand, rather than to predict the exact transient pressure during filling. It assumes a rigid circular channel, constant viscosity, steady laminar flow, and negligible entrance, connector, and compliance effects. In practice, deviations may occur because the actual filling path includes connectors and transitions, the syringe and plunger seal can deform under load, and the filling medium may show temperature- or shear-rate-dependent viscosity behavior. In addition, start-up delay, compliance-related behavior, response-time limitations, and accessory-dependent effects are known limitations of syringe-based delivery systems [10, 11]. The model is therefore treated as a design-oriented approximation for identifying how viscosity, cannula geometry, filling volume, and extrusion duration shift the operating conditions of the syringe actuator.

The calculated pressure values are therefore interpreted as theoretical estimates for process design, not as direct measurements or exact predictions of the real filling pressure. The model identifies the dominant dependencies between viscosity, flow rate, cannula geometry, and pressure demand. These pressure-related estimates are then translated into plunger force,

2. Foundations and State of the Art | 17

actuator capability, and viscosity-dependent motion parameters in the following sections.

## 2.3 Force Transmission and Mechanical Limits of Syringe Systems

During cannula-based extrusion, the pressure required to move the filling medium is converted into an axial load on the syringe plunger. In the developed platform, this load is not carried by a rigid industrial dosing cartridge, but by a disposable B. Braun 2 mL syringe and its associated mechanical interfaces. The plunger, syringe barrel, Luer Lock outlet, and plunger contact interface therefore define practical load limits for the filling process. Excessive loading may lead to plunger deformation, leakage, misalignment, or interface failure. In high-viscosity filling through a small cannula, the required extrusion force can increase substantially. Consequently, the extrusion speed used in the control strategy cannot be selected only to minimize filling time. It must also remain within a mechanically reasonable operating range for the disposable syringe, the plunger contact interface, and the connected cannula path. Similar dependencies have been reported in syringe and injection-device studies, where viscosity, syringe and needle geometry, plunger friction, and back pressure influence the required extrusion or injection force [17, 18, 19].

### 2.3.1 Pressure-Induced Plunger Force

The pressure difference required for cannula-based extrusion acts on the effective internal cross-sectional area of the syringe barrel. As illustrated in Figure 8, this pressure contribution is converted into an axial force component that must be generated by the actuator and transmitted through the plunger contact interface.

Figure 8: Pressure-to-force transmission on the syringe plunger. The pressure difference required for cannula-based extrusion acts on the effective syringe cross-sectional area As and results in the pressure-induced axial force component Fp
. The figure was created by the author.

The estimated pressure drop can be converted into an equivalent plunger force by using the internal cross-sectional area of the syringe barrel:

Fp = Fp,hyd = ∆pcAs = ∆pcπR² s

(2.9)

2. Foundations and State of the Art | 18

where Fp,hyd is the pressure-related component of the plunger force, ∆pc
is the estimated
cannula pressure drop, As
is the internal cross-sectional area of the syringe barrel, and Rs is
the inner radius of the syringe barrel.

Substituting the pressure drop from Equation 2.4 gives

Fp,hyd =

8µLcQR²
s
r

4
c

(2.10)

where µ is the dynamic viscosity, Lc is the effective cannula length, Q is the volumetric flow rate, and rc
is the inner radius of the cannula. The fourth-power dependence on the cannula radius further indicates that the small cannula required by the application is not merely a geometric interface, but a dominant factor in the mechanical loading of the syringe actuation system.

The force calculated in Equation 2.10 represents only the pressure-related force component. In a real syringe system, the actuator must also overcome additional force components, including plunger friction, seal deformation, guide friction, and acceleration-related dynamic loads. Therefore, the total actuation force can be interpreted conceptually as

Fact ≈ Fp,hyd + Ffric + Fdyn | (2.11)

where Ffric represents friction-related contributions and Fdyn represents transient dynamic loads. Because the developed system does not include a force sensor, Equation 2.11 is not used as an identified quantitative force model. Instead, the equation is used to show which load components may become limiting when the extrusion speed is increased.

For the present design, Equation 2.10 is mainly used to relate the selected flow rate to the pressure-related load on the syringe plunger. For a fixed filling volume, a higher flow rate reduces the extrusion duration, but it also increases the pressure-induced force that the actuator must generate and transfer through the plunger contact interface. This trade-off is especially important in the present application. Since the small implant dimensions require a small cannula, the fourth-power dependence on the cannula radius can strongly limit the feasible flow-rate range when high-viscosity oils are used.

### 2.3.2 Buckling Limit of the Syringe Plunger

The disposable syringe plunger also introduces an axial stability limit. During high-viscosity extrusion, the actuator pushes the plunger in the axial direction, while the resistance of the filling medium generates a reaction load through the syringe system. If this load becomes too high, the plunger may bend laterally instead of transferring the actuator motion reliably into pressure build-up and material flow. The critical load for an ideal slender member can be estimated with Euler’s buckling [22]:

Fcrit =

π

2EI

# (KLp)

2

(2.12)

where Fcrit is the critical buckling force, E is the Young’s modulus of the plunger material, I is the second moment of area of the plunger cross-section about the weakest bending axis,

2. Foundations and State of the Art | 19

Lp

is the unsupported plunger length, and K is the effective length factor determined by the boundary conditions.

The effective length factor K represents the idealized end constraints of the compressed plunger. Since the actual contact between the plunger and the actuator interface cannot be treated as a rigid moment-transmitting clamp, different boundary assumptions lead to different design estimates of the critical load. Figure 9 illustrates the typical boundary conditions used for the design-oriented comparison in this thesis.

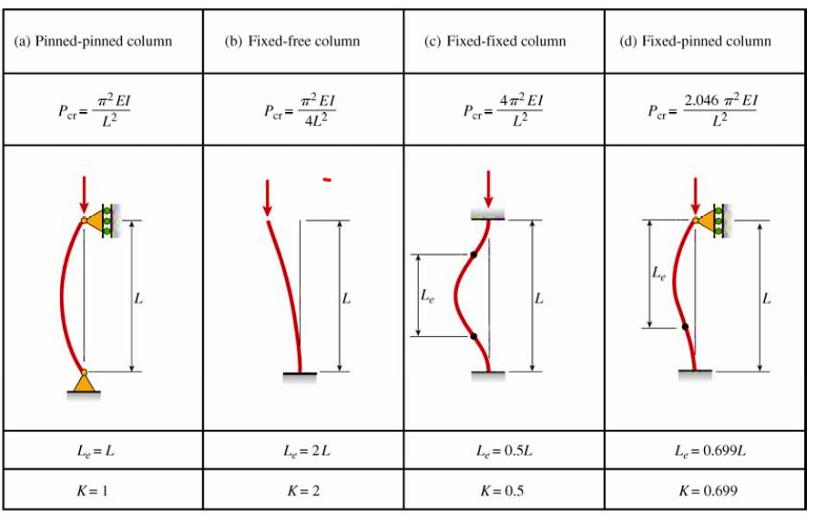
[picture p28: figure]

Figure 9: Buckling boundary conditions and corresponding effective buckling lengths for different column end constraints. The effective length factor K depends on whether the column ends are pinned, fixed, free, or partially constrained. Reproduced from [23].

In the developed syringe pump setup, the syringe barrel is fixed near the outlet side, while the plunger is pushed from the opposite side by a flat plunger contact interface. This interface transfers axial load but does not rigidly clamp the plunger or reliably transmit a bending moment. A fixed–fixed assumption would therefore overestimate the plunger stability. For the design calculation, the pinned–pinned case with K = 1.0 is used as the reference assumption. The resulting value is interpreted as a conservative design estimate relative to a fixed–fixed model, not as an experimentally verified failure load.

The unsupported plunger length Lp
is also relevant because the critical buckling force decreases with the square of the effective length. In practice, the unsupported length changes with the plunger position during the filling sequence. For a conservative design estimate, Lp should therefore be selected as the maximum unsupported length occurring within the relevant operating range. The second moment of area I should also correspond to the weakest bending direction of the actual plunger geometry, especially when the plunger has a ribbed or non-circular cross-section. Because the disposable plunger geometry and contact conditions are simplified in the Euler model, the calculated force is used only as an approximate design limit.

2. Foundations and State of the Art | 20

To avoid operation close to the estimated structural limit, a safety factor is introduced. The allowable plunger force is defined as

Fallow =

Fcrit
S

(2.13)

where S is the safety factor. The process parameters should therefore be selected so that the expected pressure-related and friction-related loads remain below the allowable plunger force. In the present system, this limit is related not only to plunger buckling but also to possible barrel deformation, plunger-seal leakage, Luer Lock interface loading, and failure of the connected filling path.

The buckling calculation is not used as a complete structural verification of the disposable syringe, because the actual plunger geometry, material data, and contact conditions are represented only in simplified form. Instead, it provides a mechanical boundary condition for process planning. Together with the pressure-induced force model, it supports the selection of viscosity-dependent motion parameters that remain within a mechanically reasonable operating range for the syringe, plunger contact interface, and actuator system.

### 2.3.3 Maximum Allowable Flow Rate

By combining the pressure-induced plunger force with the allowable force, a maximum allowable volumetric flow rate can be estimated. Setting Fp ≤ Fallow and rearranging Equation 2.10 gives

Qmax =

Fallowr

4
c
8µLcR²
s

(2.14)

Equation 2.14 is used in this thesis for selecting a flow-rate range that does not intentionally exceed the estimated plunger load limit. For the selected syringe and cannula geometry, the allowable flow rate decreases with increasing viscosity and cannula length, while it increases strongly with the inner radius of the cannula. A larger syringe barrel radius also reduces the allowable flow rate, because the same pressure drop acts on a larger plunger area and therefore produces a higher axial load.

Only the pinned–pinned, fixed–pinned, and fixed–fixed cases are included in the flow-rate comparison, since the fixed–free case does not represent the support condition of the developed syringe pump. Figure 10 shows the maximum allowable volumetric flow rate as a function of dynamic viscosity for different assumed plunger boundary conditions. The curves should not be interpreted as selectable operating modes of the developed pump. They are included to show the sensitivity of the calculated flow-rate limit to the assumed plunger support condition.

As shown in Figure 10, the maximum allowable flow rate decreases strongly with increasing viscosity. The assumed boundary condition affects the allowable plunger force and therefore the feasible flow rate. The fixed–fixed case gives the highest theoretical flow-rate limit, while the pinned–pinned case is the most conservative of the three displayed cases. Since the actual plunger support in the developed setup cannot be regarded as fully fixed, the pinned–pinned condition is used as the reference case for estimating a mechanically conservative operating range.

2. Foundations and State of the Art | 21

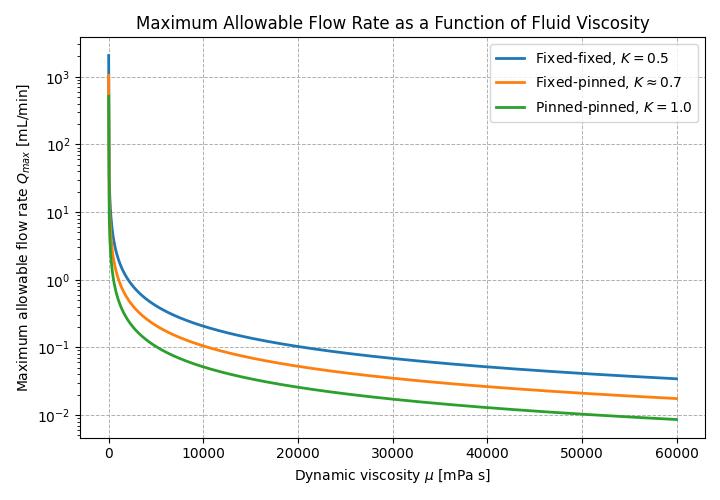
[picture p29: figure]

Figure 10: Influence of the assumed plunger boundary condition on the maximum allowable volumetric flow rate as a function of dynamic viscosity. The figure was calculated and created by the author.

For a defined target filling volume, the minimum theoretical extrusion time can be estimated as

tmin =

V

Qmax

(2.15)

where V is the target filling volume. This relationship provides a theoretical lower bound for the extrusion duration under the selected fluidic and mechanical assumptions. In practical operation, the actual extrusion time may be longer because of plunger friction, compliance, start-up effects, and additional safety margins.

### 2.3.4 Dynamic Load Limitation

In addition to quasi-static extrusion forces, actuator acceleration can introduce dynamic loads into the syringe system. In a complete force balance, the available margin for acceleration would depend on the pressure-induced force, friction-related force components, and the allowable mechanical load. Since these quantities are not directly measured in the present setup, the acceleration limit is not calculated from a complete residual-force balance. Instead, the inertial load is used as a separate design indicator according to Newton’s second law:

Finertia = meffa | (2.16)

where meff is the effective moving mass of the actuator-plunger system and a is the axial acceleration of the plunger.

If the allowable force is used only as an upper reference for the separately considered inertial

2. Foundations and State of the Art | 22

contribution, a reference acceleration can be estimated as

aref =

Fallow

meff

(2.17)

This value is not interpreted as the maximum physically admissible acceleration during extrusion, because part of the allowable force is already consumed by pressure-induced and friction-related loads. Instead, it is used as a design indicator for avoiding unnecessarily abrupt start-up, stopping, or velocity transitions. The acceleration limit is therefore treated as a conservative motion-planning constraint rather than as a complete structural force balance.

For the developed syringe pump, the equations in this section are used to constrain the selection of motion parameters before experimental compensation is applied. The actuator profile must deliver the target volume through the small cannula, but the selected flow rate and acceleration must remain compatible with the disposable syringe, the plunger contact interface, and the connected filling path. The control problem is therefore treated as a mechanically constrained extrusion task rather than a purely kinematic positioning task.

## 2.4 Existing Syringe Pump Systems and Dispensing Concepts

Syringe pump systems are established tools for delivering defined liquid volumes in laboratory, biomedical, and manufacturing environments. Their basic operating principle is to move the syringe plunger linearly with a motor-driven actuator. If the syringe geometry is known, the commanded plunger velocity and travel distance can be converted into a theoretical flow rate and displaced volume. This displacement-based principle makes syringe pumps suitable for infusion, dosing, dispensing, and experimental fluid-handling tasks. In practice, however, the delivered output is not determined by actuator motion alone. It is also affected by syringe mechanics, outlet-path resistance, and the transient behavior of the syringe–fluid system [24, 25].

For low-viscosity fluids and moderate outlet resistance, the displaced volume inside the syringe can often be treated as a reasonable approximation of the delivered volume. This assumption becomes less reliable when high-viscosity media are extruded through a small cannula. Under these conditions, pressure build-up, plunger friction, syringe compliance, cannula flow resistance, and delayed material release can all cause deviations between commanded plunger displacement and actual delivered volume. The nominal positioning accuracy of a syringe pump therefore does not necessarily translate directly into volume accuracy at the cannula outlet.

Existing approaches can be grouped into three categories: conventional syringe pump systems, high-viscosity dispensing and industrial dispensing systems, and manual or semi-automated filling approaches. Conventional syringe pump systems provide syringe-based displacement control, but they usually do not treat viscosity-dependent effects, pressure-induced deformation, or delayed extrusion as primary process variables. High-viscosity dispensing and industrial dispensing systems address viscous-material metering more directly, but many of them are based on dispensing, potting, progressive-cavity, valve-based, or piston-metering principles. They do not usually use a disposable syringe as both the fluid reservoir and the

2. Foundations and State of the Art | 23

mechanical actuation interface. Manual and semi-automated filling approaches are flexible during early laboratory work, but they depend strongly on operator handling and provide limited process traceability.

These approaches are not considered direct replacements for the platform developed in this thesis. They are used instead to define the technical gap between general syringe-based displacement control and application-specific high-viscosity implant filling. For the filling task considered in this work, the required platform must link the target filling volume, fluid viscosity, syringe geometry, cannula resistance, mechanical constraints, and experimentally determined compensation factors to an executable and verifiable actuation strategy. Section 3.2 will compare these existing approaches using representative commercial examples and figures.

## 2.5 Control Strategies for Extrusion Processes

In the present filling task, extrusion control addresses the mismatch between commanded plunger motion and material output at the cannula outlet. The controller commands the syringe plunger, but the actual extrusion behavior depends on the coupled interaction of plunger displacement, fluid viscosity, cannula resistance, plunger friction, syringe compliance, and transient pressure build-up. For this reason, the control problem in high-viscosity syringe filling cannot be reduced to a purely kinematic positioning task. It must also define how the plunger motion is planned, limited, and observed during the filling sequence.

In syringe-based dispensing, open-loop displacement control is a common and direct control strategy. Its basic principle is to convert a target delivery volume into an axial plunger displacement based on the known syringe barrel geometry. The actuator then executes this displacement without continuously correcting the plunger motion from real-time process feedback, such as measured flow rate, pressure, or dispensed volume. This approach is simple, transparent, and cost-effective. It can be sufficient for many standard syringe dispensing tasks, especially when the flow resistance is low, the outlet path is not strongly restricted, and the actual fluid output follows the commanded plunger motion with acceptable accuracy.

The filling task considered in this thesis goes beyond these typical operating conditions. When high-viscosity oil is extruded through a small cannula, the flow resistance increases substantially. Pressure build-up, plunger friction, syringe compliance, outlet resistance, back pressure, and delayed extrusion can all contribute to deviations between commanded plunger displacement and actual delivered volume. These effects become more relevant when the target filling volume is small, because even a short delay or a small elastic deformation may represent a noticeable fraction of the target volume. Studies on injection force and injectability also show that fluid viscosity, syringe geometry, needle or cannula dimensions, plunger friction, and back pressure influence the force required for syringe-based delivery [17, 18, 19]. Open-loop displacement control is therefore used as the starting point rather than as a complete control description. In the developed system, it is extended with viscosity-dependent actuation parameters and compensation to reduce the conversion error between plunger displacement and actual output under high-viscosity, small-cannula conditions.

Because direct flow and pressure feedback are not available in the present system, model-based feedforward planning is used as an extension of open-loop displacement control. This planning step defines suitable actuation parameters before the filling sequence starts, using the target filling volume, syringe geometry, cannula geometry, and fluid viscosity as input

2. Foundations and State of the Art | 24

information. The fluid-mechanical and force-transmission models introduced in the previous sections provide estimates of pressure demand, plunger force, and feasible flow-rate range. These estimates help to avoid using the same fixed plunger velocity for all viscosity conditions. Related work on high-viscosity robotic fluid deposition has also shown that model-based compensation can be useful when material response and system dynamics create deviations between actuator commands and actual output [26]. In contrast to systems with vision-based flow sensing or real-time output correction, the present thesis uses a pre-parameterized feedforward strategy. The model is used to constrain and adjust syringe actuation before extrusion, making open-loop displacement control more suitable for high-viscosity oil delivery through a small cannula.

For high-viscosity syringe filling, the shape of the actuator motion profile is also relevant. Abrupt velocity changes may introduce unnecessary dynamic loading, promote pressure peaks, or increase deformation at the syringe plunger and connected filling path. The motion command should therefore include defined acceleration and deceleration phases. The target velocity should not be reached by an instantaneous step change. In the developed system, this motion planning is used to reduce abrupt mechanical loading and to keep the extrusion process within a mechanically reasonable operating window. The purpose of the motion profile is not to implement a fully optimized dynamic controller, but to provide a controlled and reproducible actuation sequence that is compatible with the disposable syringe, the plunger contact interface, and the small cannula.

The control strategy implemented in this work is described as model-based open-loop extrusion control. In this strategy, the extrusion command is not defined directly by a fixed velocity or a fixed dispensing time. Instead, it is calculated before the start of extrusion based on the selected filling volume, fluid viscosity, syringe geometry, cannula geometry, and experimentally determined compensation factors. The geometric volume relation is used to convert the target filling volume into a theoretical plunger displacement, while the fluid-mechanical and force-transmission models are used to estimate the pressure demand, plunger force, and acceptable actuation range. Since no real-time flow or pressure feedback is used in this work, the extrusion process is not corrected during execution based on the actual output state. Systematic deviations between the theoretical model and the practical filling result are therefore addressed mainly through predefined compensation factors. The resulting strategy combines geometric volume calculation, viscosity-dependent process planning, mechanical load limitation, and experimental compensation for high-viscosity filling through a small cannula.

## 2.6 Embedded Systems and User Interfaces for Laboratory Devices

In a viscosity-controlled syringe pump, the embedded system not only drives the actuator but also converts the user-defined filling task into a reproducible process sequence. Compared with a computer-based test bench, a compact embedded platform integrates actuator control, motor-driver communication, current monitoring, parameter handling, and user interaction directly in the device. This integration is important for the present filling task because the target volume, viscosity, syringe geometry, cannula geometry, compensation factors, and motion limits must be processed consistently before the syringe plunger is moved. The embedded controller therefore links the selected process parameters to the physical extrusion process.
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

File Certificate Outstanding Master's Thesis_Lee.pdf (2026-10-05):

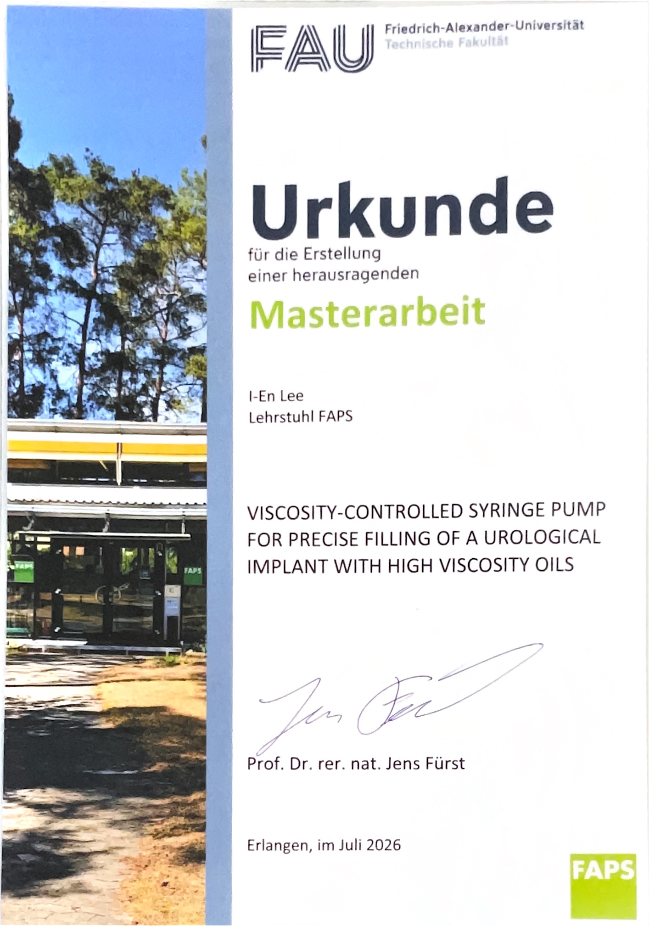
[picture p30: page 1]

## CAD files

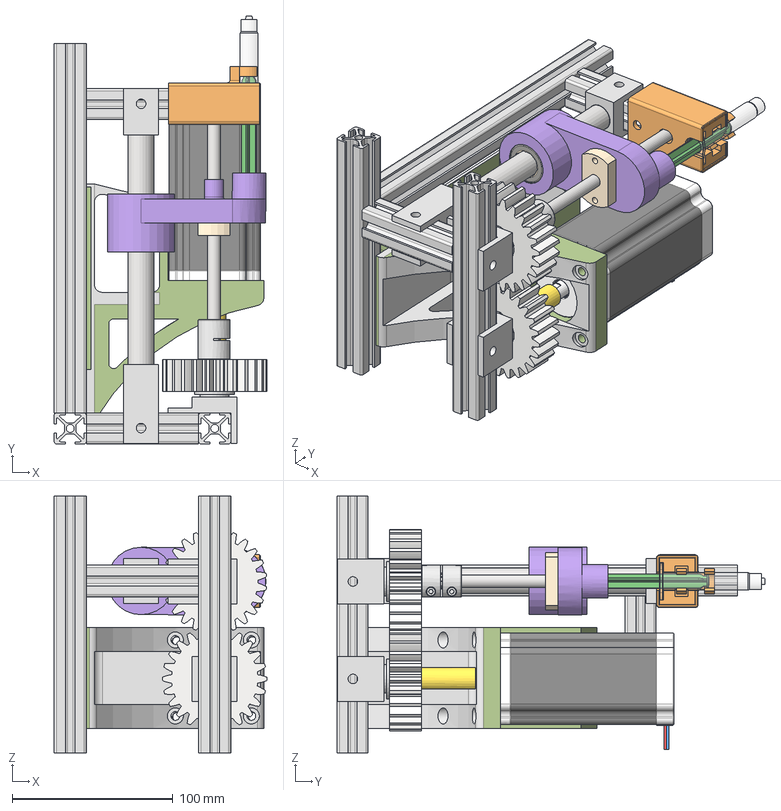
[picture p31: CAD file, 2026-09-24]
CAD Files/syringe pump for high viscosity oils.stp
132.4 x 266.6 x 160.0 mm
Aluminum profile_160mm x 3
bearing_place_v3_B
bearing_place_v3_A
Aluminum profile_70mm x 3
Aluminum profile_230mm
Kugellager_608ZZ x 2
SpurGearPair_FloatBottom_v4_insert(FDM)_test x 2
SpurGearPair_FloatBottom_v4_insert(FDM) x 2
gear_motorshaft_connector
Wellenkupplung_GX2025-8-10
Trapezgewindespindel_PTGSG08X1.501R150ES
guide rod
Edelstahlwelle_EEWM16150_
Gleitlager_RJUM_01_16_2
syringe_push_plane_V2
Flanschgewindemutter_JFRM_202020TR8X1_5_1
guide rod_upper
syringe_holder
motor holder_3DPrintVersion
gear_motorshaft_connector_1
23HS45-4204S
syringe_small_plunger
syringe_small_barrel

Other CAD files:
CAD Files/Aluminum profile_160mm.ipt
CAD Files/Aluminum profile_230mm.ipt
CAD Files/Aluminum profile_70mm.ipt
CAD Files/Edelstahlwelle_EEWM16150_.ipt
CAD Files/Flanschgewindemutter_JFRM_202020TR8X1_5_1.ipt
CAD Files/Gleitlager_RJUM_01_16_2.ipt
CAD Files/Kugellager_608ZZ.ipt
CAD Files/Schrittmotor_Nema23-03.ipt
CAD Files/SpurGear.ipt
CAD Files/SpurGear_bearing_connectort.ipt
CAD Files/Trapezgewindespindel_PTGSG08X1.501R150ES.ipt
CAD Files/Wellenkupplung_GX2025-8-10.ipt
CAD Files/bearing_place_CylinderSide.ipt
CAD Files/bearing_place_MotorSide.ipt
CAD Files/gear_motorshaft_connector_CylinderSide.ipt
CAD Files/gear_motorshaft_connector_MotorSide.ipt
CAD Files/guide rod_lower.ipt
CAD Files/guide rod_upper.ipt
CAD Files/motor holder.ipt
CAD Files/syringe pump for high viscosity oils.iam
CAD Files/syringe_holder.ipt
CAD Files/syringe_push_plane.ipt
CAD Files/syringe_small_barrel.ipt
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

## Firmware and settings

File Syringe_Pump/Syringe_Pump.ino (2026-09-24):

//#include "arduino_secrets.h"

#define LV_CONF_INCLUDE_SIMPLE

#include "lv_conf.h"
#include "Arduino_H7_Video.h"
#include "Arduino_GigaDisplayTouch.h"
#include "lvgl.h" //LVGL version 8.3.10
#include "fonts.h"
#include "images.h"
#include "FlowConstraintModel.h"
#include "PlungerMotionPlanner.h"
#include "TmcExecutableRampPlanner.h"
#include "RealtimeCurveRenderer.h"
#include "MotorControlScreen.h"
#include "CustomizedParametersScreen.h"
#include "MotionModeManager.h"
#include "FanControl.h"

// ====== For Planner Value Monitor =====
#define DEBUG_PLANNER 1
// ======================================

// --- Global Variables ---
// struct put before all function
typedef struct{
  const char** keymap;          // keypad layout
  lv_align_t align;             // keypad align mode
  lv_coord_t x_ofs;             // keypad x offset
  lv_coord_t y_ofs;             // keypad y offset
  bool allow_decimal;           // allow "."
  bool allow_double_zero;       // allow "00"
  uint8_t max_chars;            // max input length, 0 = no limit
} keypad_config_t;

typedef struct{
  lv_obj_t* display_label; // area to show value
  lv_obj_t* textarea;      // user input
  lv_obj_t* options_btn;
  lv_obj_t* list;
  lv_obj_t* keyboard;      // dedicated keypad
  const keypad_config_t* keypad_cfg; // keypad config for this block
  bool has_options;
}input_block_t;

typedef struct{
  const char* title;
  const char* value;
}option_item_t;

// struct for numeric keypad
static const char * num_kb_map[] = {
    "1", "2", "3", LV_SYMBOL_BACKSPACE, "\n",
    "4", "5", "6", LV_SYMBOL_BACKSPACE, "\n",
    "7", "8", "9", LV_SYMBOL_NEW_LINE, "\n",
    "0", "00", ".", LV_SYMBOL_NEW_LINE, ""
};

static const char * viscosity_kb_map[] = {
    "1", "2", "3", LV_SYMBOL_BACKSPACE, "\n",
    "4", "5", "6", LV_SYMBOL_BACKSPACE, "\n",
    "7", "8", "9", LV_SYMBOL_NEW_LINE, "\n",
    "0", "00", "000", LV_SYMBOL_NEW_LINE, ""
};

static const char * quantity_kb_map[] = {
    "1", "2", "3", LV_SYMBOL_BACKSPACE, "\n",
    "4", "5", "6", LV_SYMBOL_BACKSPACE, "\n",
    "7", "8", "9", LV_SYMBOL_NEW_LINE, "\n",
    "0", "00", "000", LV_SYMBOL_NEW_LINE, ""
};

static const keypad_config_t viscosity_keypad_cfg = {
    viscosity_kb_map,
    LV_ALIGN_BOTTOM_MID,
    160,
    -50,
    false,   // allow decimal
    true,  // allow "00"
    5       // max chars
};

static const keypad_config_t quantity_keypad_cfg = {
    quantity_kb_map,
    LV_ALIGN_BOTTOM_MID,
    -160,
    -50,
    false,  // no decimal
    true,   // allow "00"
    4       // max chars
};

// --- Tab ---
lv_obj_t* tab1;
lv_obj_t* tab2;
lv_obj_t* tab3;
// --- Screen navigation ---
static lv_obj_t* main_screen = NULL;
static lv_obj_t* manual_screen_tab1 = NULL;
static lv_obj_t* manual_screen_tab2 = NULL;
static lv_obj_t* manual_screen_tab3 = NULL;
// --- START / STOP state ---
static bool is_running = false;
static lv_obj_t* start_btn = NULL;
static lv_obj_t* confirm_dialog = NULL;
// --- Retraction / Backdraw mode ---
static lv_obj_t* retract_switch = NULL;
static lv_obj_t* retract_switch_label = NULL;

static bool retract_mode_enabled = false;        // UI目前設定
static bool run_retract_mode_enabled = false;    // 本次運行鎖定的設定

static bool retract_move_started = false;

static const float RETRACT_DISTANCE_MM = 3.0f; // retract distance
static const float RETRACT_MAX_VELOCITY_MM_S = 0.20f;
static const float RETRACT_ACCEL_MM_S2 = 0.1f;
static const float RETRACT_DECEL_MM_S2 = 0.1f;
// --- Extrusion fan mode ---
static lv_obj_t* extrusion_fan_switch = NULL;
static lv_obj_t* extrusion_fan_switch_label = NULL;
static lv_obj_t* manual_fan_switch = NULL;
static lv_obj_t* manual_fan_switch_label = NULL;

static bool extrusion_fan_mode_enabled = false;      // UI setting before START
static bool run_extrusion_fan_mode_enabled = false;  // locked setting for the current run

static const uint8_t FAN2_PWM_PIN = 6;              // Arduino D6 / FAN2_PWM
static const uint8_t LEVEL_SHIFTER_OE_PIN = 4;      // Arduino D4 / OE
static const uint8_t FAN_ON_DUTY = 255;             // full-speed ON for 5 V fan
// --- Recorded parameters ---
static const char* recorded_viscosity = NULL;
static const char* recorded_quantity  = NULL;
// predicted duration from motion planner
static float recorded_duration_sec_exact = 0.0f; // exact predicted duration (s)
static int   recorded_duration_sec       = 30;   // rounded duration for existing countdown logic
static bool  recorded_duration_valid     = false;
// --- Timer ---
static unsigned long run_start_ms = 0;
// --- countdown overlay ---
static lv_obj_t* finish_dialog = NULL;
static lv_obj_t* countdown_dialog = NULL;
static lv_obj_t* countdown_label  = NULL;
static lv_obj_t* countdown_ok_btn = NULL;
static unsigned long last_countdown_update = 0;
// --- System Progress UI ---
static lv_obj_t* arc_progress = NULL;
static lv_obj_t* lbl_percent = NULL;

static lv_obj_t* lbl_viscosity = NULL;
static lv_obj_t* lbl_quantity = NULL;
static lv_obj_t* lbl_remaining = NULL;
static lv_obj_t* lbl_duration = NULL;
static lv_obj_t* lbl_elapsed = NULL;
static lv_obj_t* lbl_tmc_target_distance = NULL;
static lv_obj_t* lbl_tmc_actual_distance = NULL;
// TMC distance monitor cache.
// Must be declared before show_start_confirm_dialog(), because the START lambda resets it.
static float last_tmc_target_distance_mm = 0.0f;
static float last_tmc_actual_distance_mm = 0.0f;
static bool tmc_distance_frozen_after_extrusion = false;
// --- Tab3 preview panels ---
static lv_obj_t* tab3_volume_curve_panel = NULL;
static lv_obj_t* tab3_current_curve_panel = NULL;
// --- Tab3 control buttons ---
static lv_obj_t* btn_tab3_parameter_setting = NULL;
static lv_obj_t* btn_tab3_motor_control = NULL;
static lv_obj_t* btn_tab3_disable_motor = NULL;
// --- Motion planner runtime ---
static PlungerMotionPlanner realtime_motion_planner;
static bool realtime_motion_planner_valid = false;

// TMC executable ramp planner
static TmcExecutableRampPlanner tmc_executable_planner;
static bool tmc_executable_planner_valid = false;
static TmcRampCommand g_tmc_ramp_cmd;

static float realtime_curve_volume_max_uL = 1000.0f;
static float realtime_curve_current_max_A = 3.0f;

static unsigned long last_curve_update_ms = 0;
// --- Current tail recording after motor finish ---
static const float CURRENT_TAIL_SEC = 5.0f;      // motor finish 後多記錄 5 秒電流
static float chart_total_duration_sec = 0.0f;    // chart X 軸總時間
static bool current_tail_recording = false;
static unsigned long current_tail_start_ms = 0;
// --- Global Variables ---
input_block_t* viscosity_block;
input_block_t* quantity_block;
// --- Stop request state ---
static bool stop_requested = false;
static bool stop_requested_by_timeout = false;
static unsigned long stop_request_ms = 0;
// --- Display Duration Seconds ---
static float extrusion_duration_sec_exact = 0.0f;
static float retraction_duration_sec_exact = 0.0f;

// 主擠出 + 回抽，不含 current tail
static float operation_motion_duration_sec_exact = 0.0f;

// UI 顯示與倒數用，包含保守估算
static float display_duration_sec_exact = 0.0f;
static int   display_duration_sec = 0;

// 你目前 60000 mPas / 1 mL 實測：865.85 / 845.86 = 1.0236
// 先用 1.024 修正模型低估問題
static const float EXTRUSION_DURATION_CALIBRATION = 1.024f;
static const float RETRACTION_DURATION_CALIBRATION = 1.000f;

// 顯示給使用者看的保守 margin
static const float DISPLAY_MARGIN_RATIO = 0.25f;
static const float DISPLAY_MARGIN_MIN_SEC = 3.0f;

// phase timeout margin
// 一般 phase timeout 使用比例型 margin，不再使用固定 240 s 上限。
static const float TIMEOUT_MARGIN_RATIO = 0.30f;
static const float TIMEOUT_MARGIN_MIN_SEC = 30.0f;

// 開啟 retraction 時，主擠出 phase 使用更寬鬆的比例型 timeout。
// 目的：避免長時間高黏度擠出在 motionFinished() 之前被 timeout stop，導致 retraction 無法觸發。
static const float RETRACTION_EXTRUSION_TIMEOUT_RATIO = 0.50f;
static const float RETRACTION_EXTRUSION_TIMEOUT_MIN_SEC = 300.0f;

// Clear residual value of countdown
static bool system_progress_force_remaining_zero = false;
static bool system_progress_force_complete = false;
static bool system_progress_tail_ramp_active = false;
static float system_progress_tail_start_percent = 0.0f;
static unsigned long system_progress_tail_start_ms = 0;

// retarct manager
enum RunPhase {
    RUN_PHASE_IDLE,
    RUN_PHASE_EXTRUDING,
    RUN_PHASE_RETRACTING,
    RUN_PHASE_TAIL_RECORDING
};
//

static RunPhase run_phase = RUN_PHASE_IDLE;
static unsigned long phase_start_ms = 0;

typedef struct {
    const char* key;
    const char* unit;
    const char* default_str;   // 預設值（字串）
    char saved_str[32];        // 已儲存值
} dev_param_value_t;

// --- Build Screen ---
typedef struct {
    lv_obj_t** target_screen;
    void (*screen_builder)();
} nav_btn_ctx_t;
// --- Static Context Pool ---
static nav_btn_ctx_t nav_btn_ctx_pool[8];
static uint8_t nav_btn_ctx_count = 0;
static input_block_t input_block_pool[4];
static uint8_t input_block_count = 0;
// --------------------------------------

// --- Display Shield Initialization  ---
Arduino_H7_Video Display(800, 480, GigaDisplayShield);
Arduino_GigaDisplayTouch TouchDetector;
// --------------------------------------

// --- Multi-Tab Initialization ---
void lv_initial_tabview(void){
  lv_obj_t* tabview = lv_tabview_create(lv_scr_act(), LV_DIR_TOP, 80);
  lv_obj_t* tab_btns = lv_tabview_get_tab_btns(tabview);
  lv_obj_set_style_text_font(tab_btns, &montserrat_22, 0);
  (void)tab_btns;

  tab1 = lv_tabview_add_tab(tabview, "SETTING");
  lv_obj_clear_flag(tab1, LV_OBJ_FLAG_SCROLLABLE);
  tab2 = lv_tabview_add_tab(tabview, "SYSTEM PROGRESS");
  lv_obj_clear_flag(tab2, LV_OBJ_FLAG_SCROLLABLE);
  tab3 = lv_tabview_add_tab(tabview, "DEVELOPER INFO");
  lv_obj_clear_flag(tab3, LV_OBJ_FLAG_SCROLLABLE);
}
// --------------------------------------

// --- Fan Declaration ---
static void set_extrusion_fan_switch_enabled(bool enabled);
static void set_manual_fan_switch_enabled(bool enabled);
static void sync_manual_fan_switch_to_actual_state();
static void stop_fan_and_sync_ui();
// -----------------------

// --- START / STOP Button ---
static void start_btn_event_cb(lv_event_t* e)
{
    lv_obj_t* btn = lv_event_get_target(e);

    if (!is_running) {
        fetch_setting_values();

        if (!recorded_viscosity) {
            show_missing_param_dialog("Missing liquid viscosity");
            return;
        }

        if (!recorded_quantity) {
            show_missing_param_dialog("Missing extrusion quantity");
            return;
        }

        float viscosity_value = atof(recorded_viscosity);
        float quantity_value  = atof(recorded_quantity);

        if (viscosity_value <= 0.0f) {
            show_missing_param_dialog("Invalid liquid viscosity");
            return;
        }

        if (quantity_value <= 0.0f) {
            show_missing_param_dialog("Invalid extrusion quantity");
            return;
        }

        auto tr = MotionModeManager::requestScenario(
            MotionModeManager::SCENARIO_EXTRUSION_ACTIVE
        );

        if (!tr.success) {
            show_missing_param_dialog(tr.message);
            return;
        }

        // 鎖定本次確認視窗使用的回抽模式
        run_retract_mode_enabled = retract_mode_enabled;
        run_extrusion_fan_mode_enabled = extrusion_fan_mode_enabled;

        if (!calculate_predicted_duration()) {
            MotionModeManager::forceIdle("Failed to build extrusion planner");
            show_missing_param_dialog("Failed to build extrusion planner");
            return;
        }

        // 確認視窗打開後，不允許再改回抽模式
        set_retract_switch_enabled(false);
        set_extrusion_fan_switch_enabled(false);
        set_manual_fan_switch_enabled(false);

        show_start_confirm_dialog(btn);  
    }
    else {
        show_confirm_dialog(btn, tab1);
    }
}

void create_start_button(lv_obj_t* parent, lv_coord_t x, lv_coord_t y)
{
    start_btn = lv_btn_create(parent);
    lv_obj_set_size(start_btn, 250, 60);
    lv_obj_align(start_btn, LV_ALIGN_BOTTOM_MID, x, y);
    lv_obj_set_style_bg_color(start_btn, lv_color_hex(0x0000FF), 0);

    lv_obj_add_event_cb(start_btn, start_btn_event_cb, LV_EVENT_CLICKED, NULL);

    lv_obj_t* label = lv_label_create(start_btn);
    lv_label_set_text(label, "START");
    lv_obj_set_style_text_font(label, &montserrat_30, 0);
    lv_obj_center(label);
}

static void update_retract_switch_label()
{
    if (!retract_switch_label) return;

    lv_label_set_text(
        retract_switch_label,
        retract_mode_enabled ? "Retraction: ON" : "Retraction: OFF"
    );
}

static void retract_switch_event_cb(lv_event_t* e)
{
    lv_obj_t* sw = lv_event_get_target(e);

    retract_mode_enabled = lv_obj_has_state(sw, LV_STATE_CHECKED);

    update_retract_switch_label();
}
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
void loop()
{
    lv_timer_handler();

    // =============================
    // PRIORITY: user stop request
    // =============================
    if (stop_requested)
    {
        bool stopped = MotorControlScreen::motionFinished();

        bool stop_wait_timeout =
            (millis() - stop_request_ms > 3000);

        if (stopped || stop_wait_timeout)
        {
            const bool was_timeout_stop = stop_requested_by_timeout;

            if (stop_wait_timeout && !stopped) {
                MotorControlScreen::forceStopState();
            }

            stop_requested = false;
            stop_requested_by_timeout = false;
            is_running = false;

            run_phase = RUN_PHASE_IDLE;
            phase_start_ms = 0;
            current_tail_recording = false;
            current_tail_start_ms = 0;
            retract_move_started = false;

            const char* stop_reason = "Stopped";

            if (was_timeout_stop) {
                stop_reason = stop_wait_timeout
                    ? "Timeout stop failed"
                    : "Extrusion timeout stopped";
            }
            else {
                stop_reason = stop_wait_timeout
                    ? "Stop timeout"
                    : "User stopped";
            }

            MotionModeManager::forceIdle(stop_reason);

            recorded_duration_valid = false;
            realtime_motion_planner_valid = false;
            tmc_executable_planner_valid = false;
            g_tmc_ramp_cmd = TmcRampCommand();

            set_tab3_control_buttons_enabled(true);

            stop_fan_and_sync_ui();

            set_retract_switch_enabled(true);
            set_extrusion_fan_switch_enabled(true);
            set_manual_fan_switch_enabled(true);

            retract_move_started = false;

            if (RealtimeCurveRenderer::isInitialized()) {
                RealtimeCurveRenderer::releaseTempData();
            }

            if (start_btn)
            {
                lv_obj_t* label = lv_obj_get_child(start_btn, 0);
                lv_label_set_text(label, "START");
                lv_obj_set_style_bg_color(
                    start_btn,
                    lv_color_hex(0x0000FF),
                    0
                );
            }

            clear_countdown_dialog();
            show_finish_dialog();
        }

        MotorControlScreen::update();
        delay(5);
        return;
    }

    // =============================
    // Normal runtime logic
    // =============================
    if (is_running) {
        float phase_elapsed_s =
            (millis() - phase_start_ms) / 1000.0f;

        bool finished_by_motor =
            MotorControlScreen::motionFinished();
        //
        if (run_phase == RUN_PHASE_EXTRUDING) {

            if (finished_by_motor) {

                // Fan stops immediately when the extrusion motion reports motionFinished().
                stop_fan_and_sync_ui();

                // Freeze extrusion-end TMC target / actual distance.
                // Do this before retraction starts, otherwise the retraction target
                // will overwrite the displayed extrusion-end values.
                freeze_tmc_distance_at_extrusion_end();

                if (run_retract_mode_enabled) {
                    retract_move_started = true;

                    if (!start_retract_move_4mm()) {
                        MotionModeManager::forceIdle("Retraction failed");

                        is_running = false;
                        current_tail_recording = false;
                        retract_move_started = false;
                        run_phase = RUN_PHASE_IDLE;
                        phase_start_ms = 0;

                        recorded_duration_valid = false;
                        realtime_motion_planner_valid = false;
                        tmc_executable_planner_valid = false;
                        g_tmc_ramp_cmd = TmcRampCommand();

                        set_tab3_control_buttons_enabled(true);

                        stop_fan_and_sync_ui();

                        set_retract_switch_enabled(true);
                        set_extrusion_fan_switch_enabled(true);
                        set_manual_fan_switch_enabled(true);

                        if (start_btn) {
                            lv_obj_t* label = lv_obj_get_child(start_btn, 0);
                            lv_label_set_text(label, "START");
                            lv_obj_set_style_bg_color(start_btn, lv_color_hex(0x0000FF), 0);
                        }

                        clear_countdown_dialog();
                        show_missing_param_dialog("Retraction failed");

                        MotorControlScreen::update();
                        delay(5);
                        return;
                    }

                    run_phase = RUN_PHASE_RETRACTING;
                    phase_start_ms = millis();

                    MotorControlScreen::update();
                    delay(5);
                    return;
                }
                
                begin_system_progress_tail_ramp();

                current_tail_recording = true;
                current_tail_start_ms = millis();
                run_phase = RUN_PHASE_TAIL_RECORDING;
                phase_start_ms = millis();
            }
            else {
                float extrusion_timeout_margin_s =
                    calc_extrusion_timeout_margin_s(extrusion_duration_sec_exact);

                float timeout_limit_s =
                    extrusion_duration_sec_exact + extrusion_timeout_margin_s;

                if (phase_elapsed_s > timeout_limit_s) {
                    auto tr = MotionModeManager::requestScenario(
                        MotionModeManager::SCENARIO_EXTRUSION_STOPPING
                    );

                    if (!tr.success) {
                        MotionModeManager::forceIdle("Extrusion timeout");
                    }

                    MotorControlScreen::stopMotion();

                    stop_requested = true;
                    stop_requested_by_timeout = true;
                    stop_request_ms = millis();

                    MotorControlScreen::update();
                    delay(5);
                    return;
                }
            }
        }
        else if (run_phase == RUN_PHASE_RETRACTING) {
            
            if (finished_by_motor) {
                begin_system_progress_tail_ramp();

                current_tail_recording = true;
                current_tail_start_ms = millis();
                run_phase = RUN_PHASE_TAIL_RECORDING;
                phase_start_ms = millis();
            }
            else {
                float timeout_limit_s =
                    retraction_duration_sec_exact +
                    calc_timeout_margin_s(retraction_duration_sec_exact);

                if (phase_elapsed_s > timeout_limit_s) {
                    auto tr = MotionModeManager::requestScenario(
                        MotionModeManager::SCENARIO_EXTRUSION_STOPPING
                    );

                    if (!tr.success) {
                        MotionModeManager::forceIdle("Retraction timeout");
                    }

                    MotorControlScreen::stopMotion();

                    stop_requested = true;
                    stop_requested_by_timeout = true;
                    stop_request_ms = millis();

                    MotorControlScreen::update();
                    delay(5);
                    return;
                }
            }
        }
        else if (run_phase == RUN_PHASE_TAIL_RECORDING) {

            if (millis() - current_tail_start_ms >=
                (unsigned long)(CURRENT_TAIL_SEC * 1000.0f)) {

                is_running = false;
                current_tail_recording = false;
                retract_move_started = false;
                run_phase = RUN_PHASE_IDLE;
                phase_start_ms = 0;

                force_system_progress_operation_complete();

                set_tab3_control_buttons_enabled(true);

                stop_fan_and_sync_ui();

                set_retract_switch_enabled(true);
                set_extrusion_fan_switch_enabled(true);
                set_manual_fan_switch_enabled(true);

                MotionModeManager::finishCurrentScenario();

                recorded_duration_valid = false;
                realtime_motion_planner_valid = false;
                tmc_executable_planner_valid = false;
                g_tmc_ramp_cmd = TmcRampCommand();

                if (RealtimeCurveRenderer::isInitialized()) {
                    RealtimeCurveRenderer::releaseTempData();
                }
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

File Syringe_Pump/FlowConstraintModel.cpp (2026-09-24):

#include "FlowConstraintModel.h"

// =========================
// Utility
// =========================
bool FlowConstraintModel::is_valid_positive(float x)
{
    return isfinite(x) && x > 0.0f;
}

float FlowConstraintModel::safe_positive(float x)
{
    return (isfinite(x) && x > 0.0f) ? x : 0.0f;
}

float FlowConstraintModel::plunger_area_from_R(float R)
{
    return PI * R * R;
}

float FlowConstraintModel::viscosity_Pa_s_from_mPa_s(float viscosity)
{
    return viscosity / 1000.0f;
}

float FlowConstraintModel::linear_velocity_mps_from_flow(
    const Params& p,
    float Q_m3_s
)
{
    if (!is_valid_positive(p.stroke_per_ml_mm) ||
        !is_valid_positive(Q_m3_s)) {
        return 0.0f;
    }

    // Q [m^3/s] * 1e6 = mL/s
    // v [mm/s] = flow [mL/s] * stroke_per_ml_mm
    // v [m/s] = v [mm/s] / 1000
    const float flow_mL_s = Q_m3_s * 1.0e6f;
    const float v_mm_s = flow_mL_s * p.stroke_per_ml_mm;

    return v_mm_s * 1.0e-3f;
}

float FlowConstraintModel::flow_from_linear_velocity_mps(
    const Params& p,
    float v_m_s
)
{
    if (!is_valid_positive(p.stroke_per_ml_mm) ||
        !is_valid_positive(v_m_s)) {
        return 0.0f;
    }

    // v [m/s] -> v [mm/s]
    // flow [mL/s] = v [mm/s] / stroke_per_ml_mm
    // Q [m^3/s] = flow [mL/s] * 1e-6
    const float v_mm_s = v_m_s * 1000.0f;
    const float flow_mL_s = v_mm_s / p.stroke_per_ml_mm;

    return flow_mL_s * 1.0e-6f;
}

float FlowConstraintModel::estimate_plunger_second_moment(const Params& p)
{
    const float a = p.shaft;       // plunger shaft outer width [m]
    const float d = p.shaft_walls; // plunger shaft wall thickness [m]

    if (!is_valid_positive(a) || !is_valid_positive(d)) {
        return 0.0f;
    }

    if (d >= a) {
        return 0.0f;
    }

    // Conservative fallback estimate based on plunger shaft wall geometry.
    // This follows the simplified model:
    //
    // I_est = (d * a^3 + (a - d) * d^3) / 12
    //
    // Unit:
    // m * m^3 = m^4
    const float I_est =
        (d * a * a * a + (a - d) * d * d * d) / 12.0f;

    if (!is_valid_positive(I_est)) {
        return 0.0f;
    }

    return I_est;
}

// =========================
// Structure limit
// =========================
void FlowConstraintModel::calculate_struct_flow_limit(
    const Params& p,
    float& Q_struct,
    float& v_struct,
    float& F_crit,
    float& F_allow,
    float& I_used,
    bool& I_auto_estimated
)
{
    Q_struct = 0.0f;
    v_struct = 0.0f;
    F_crit   = 0.0f;
    F_allow  = 0.0f;
    I_used   = 0.0f;
    I_auto_estimated = false;

    const float mu = viscosity_Pa_s_from_mPa_s(p.viscosity); // Pa.s
    const float A  = plunger_area_from_R(p.R);               // m^2

    if (mu <= 0.0f ||
        A <= 0.0f ||
        p.r <= 0.0f ||
        p.l <= 0.0f ||
        p.R <= 0.0f ||
        p.S <= 0.0f ||
        p.L <= 0.0f ||
        p.K_buckling <= 0.0f) {
        return;
    }

    // I_plunger selection rule:
    // - If user provided a valid positive I_plunger, use it directly.
    // - If I_plunger is zero, empty, negative, NaN, or invalid, estimate it from shaft geometry.
    if (is_valid_positive(p.I_plunger)) {
        I_used = p.I_plunger;
        I_auto_estimated = false;
    } else {
        I_used = estimate_plunger_second_moment(p);
        I_auto_estimated = true;
    }

    if (!is_valid_positive(I_used)) {
        return;
    }

    F_crit  = (PI * PI * p.E * I_used) / ((p.K_buckling * p.L) * (p.K_buckling * p.L));
    F_allow = F_crit / p.S;

    // Q_max = (F_allow * r^4) / (8 * mu * l * R^2)
    const float r4 = p.r * p.r * p.r * p.r;
    Q_struct = (F_allow * r4) / (8.0f * mu * p.l * p.R * p.R);
    v_struct = linear_velocity_mps_from_flow(p, Q_struct);

    Q_struct = safe_positive(Q_struct);
    v_struct = safe_positive(v_struct);
    F_crit   = safe_positive(F_crit);
    F_allow  = safe_positive(F_allow);
}
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

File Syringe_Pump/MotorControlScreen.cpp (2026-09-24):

#include "MotorControlScreen.h"

#include <Arduino.h>
#include <Wire.h>
#include <SPI.h>
#include <TMC51X0.hpp>
#include <Adafruit_INA228.h>
#include <math.h>

#include "lvgl.h"
#include "fonts.h"

namespace {

// =========================
// Hardware config
// =========================
#define PIN_OE 4

const size_t ENABLE_HARDWARE_PIN = 7;
const uint8_t CHIP_SELECT_PIN    = 10;
const uint8_t INA228_ADDR        = 0x40;

#if defined(ARDUINO_ARCH_RP2040)
SPIClassRP2040 &spi = SPI;
size_t SCK_PIN = 13;
size_t TX_PIN  = 11;
size_t RX_PIN  = 12;
#else
SPIClass &spi = SPI1;
#endif

// leadscrew: 1.5 mm / rev
static constexpr float LEADSCREW_MM_PER_REV = 1.5f;
// TMC51X0's ControllerParameters store real-unit velocity and acceleration
// as uint32_t before conversion. Therefore very small physical values such as
// 0.007 mm/s may be truncated to zero if they are passed directly.
//
// POSITION_SCALE_FACTOR converts physical mm-based units into internal
// controller units before they enter the TMC51X0 converter.
// It is not only a distance calibration factor. It also preserves low-speed
// and low-acceleration command resolution before integer truncation.
//
// Effective physical scale:
// MICROSTEPS_PER_REAL_POSITION_UNIT * POSITION_SCALE_FACTOR
// = TMC microsteps per physical mm.
//
// Example:
// 1 microsteps/controller_unit * 35050 controller_units/mm
// = 35050 microsteps/mm.
//
// Low-speed preservation:
// 0.007 mm/s * 35050 = 245.35 controller_units/s,
// which survives uint32_t truncation as 245 instead of becoming 0.
///// ===== How to use ? ===== /////
// Standard movement(with low viscosity medium) for 13 mm: 523.35f(POSITION_SCALE_FACTOR) * 91.0f(MICROSTEPS_PER_REAL_POSITION_UNIT)
// Low Boundary of MICROSTEPS_PER_REAL_POSITION_UNIT = 70.0f
static constexpr float MICROSTEPS_PER_REAL_POSITION_UNIT = 70.0f;
// Adjustment: new_POSITION_SCALE_FACTOR = old_POSITION_SCALE_FACTOR * target_distance / actual_distance;
// POSITION_SCALE_FACTOR = 523.35f for Water & calibration standard (without retraction)
// POSITION_SCALE_FACTOR = 515.94f for 100 mPa.s
// Upper Boundary of POSITION_SCALE_FACTOR = 530.0f
static constexpr float POSITION_SCALE_FACTOR = 523.35f;

// Setting minimum value of speed
static inline float ceil_to_3_decimals(float value)
{
    return ceilf(value * 1000.0f) / 1000.0f;
}

static inline float min_executable_motion_value()
{
    return ceil_to_3_decimals(1.0f / POSITION_SCALE_FACTOR);
}

static inline float clamp_positive_to_min_executable(float value)
{
    if (value <= 0.0f) {
        return 0.0f;   // intentionally allow exact zero for startVelocity / firstVelocity
    }

    const float min_value = min_executable_motion_value();
    return (value < min_value) ? min_value : value;
}

static inline float clamp_required_to_min_executable(float value)
{
    const float min_value = min_executable_motion_value();
    return (value < min_value) ? min_value : value;
}

// Allow tolerance between target movement & actual movement
// 0.01 / 13 = 0.000769 mL = 0.769 µL (±0.077%)
// 0.01 * 35050 = 350.5 microstep (tolerance = 350 microsteps -> safe range)
static constexpr float POSITION_REACHED_TOLERANCE_MM = 0.01f;

static inline float to_controller_distance_mm(float physical_mm)
{
    return physical_mm * POSITION_SCALE_FACTOR;
}

static inline float from_controller_distance_mm(float controller_mm)
{
    return controller_mm / POSITION_SCALE_FACTOR;
}

static inline float to_controller_velocity_mm_s(float physical_mm_s)
{
    return physical_mm_s * POSITION_SCALE_FACTOR;
}

static inline float to_controller_acceleration_mm_s2(float physical_mm_s2)
{
    return physical_mm_s2 * POSITION_SCALE_FACTOR;
}

// =========================
// Runtime objects
// =========================
TMC51X0 stepper;
Adafruit_INA228 ina228;

lv_obj_t* main_screen_obj = NULL;
lv_obj_t* screen_obj      = NULL;

bool motor_spi_ready  = false;
bool motor_is_running = false;
bool motor_stop_ramping = false;
bool moving_forward_phase = true;
bool motor_driver_disabled = true;

unsigned long motor_start_ms = 0;

int32_t current_target_chip = 0;
int32_t current_home_chip   = 0;



// =========================
// Settings model
// =========================
MotorControlScreen::MotorSpiSettings g_settings = {
    75.0f,  // runCurrentPercent
    35.0f,  // pwmOffsetPercent
    15.0f,  // pwmGradientPercent
    true,   // reverseDirection
    50.0f,  // stealthChopThreshold

    0.3f,  // maxVelocity
    0.1f,   // maxAcceleration
    0.0f,   // startVelocity
    0.01f,   // stopVelocity
    0.1f,  // firstVelocity
    0.1f,   // firstAcceleration
    0.1f,   // maxDeceleration
    0.1f,   // firstDeceleration

    MotorControlScreen::MODE_DISTANCE_MM, // mode
    1.0f,   // forwardValue
    1.0f    // backwardValue
};

// =========================
// UI objects
// =========================
lv_obj_t* ta_runCurrent         = NULL;
lv_obj_t* ta_pwmOffset          = NULL;
lv_obj_t* ta_pwmGradient        = NULL;
lv_obj_t* dd_direction          = NULL;
lv_obj_t* ta_stealthThreshold   = NULL;

lv_obj_t* ta_maxVelocity        = NULL;
lv_obj_t* ta_maxAcceleration    = NULL;
lv_obj_t* ta_startVelocity      = NULL;
lv_obj_t* ta_stopVelocity       = NULL;
lv_obj_t* ta_firstVelocity      = NULL;
lv_obj_t* ta_firstAcceleration  = NULL;
lv_obj_t* ta_maxDeceleration    = NULL;
lv_obj_t* ta_firstDeceleration  = NULL;

lv_obj_t* dd_mode               = NULL;
lv_obj_t* ta_forwardValue       = NULL;
lv_obj_t* ta_backwardValue      = NULL;

lv_obj_t* lbl_status            = NULL;
lv_obj_t* btn_start             = NULL;
lv_obj_t* btn_stop              = NULL;

// shared keypad
lv_obj_t* kb_numeric            = NULL;
lv_obj_t* kb_target_ta          = NULL;

// textarea focus style
static lv_style_t st_textarea_focused;
static bool st_textarea_focused_inited = false;

// =========================
// Keypad map
// =========================
static const char * num_kb_map[] = {
    "1", "2", "3", "\n",
    "4", "5", "6", "\n",
    "7", "8", "9", "\n",
    "0", "00", ".", "\n",
    LV_SYMBOL_BACKSPACE, LV_SYMBOL_NEW_LINE, ""
};

// =========================
// Helpers
// =========================
void init_textarea_focus_style()
{
    if (st_textarea_focused_inited) return;
    st_textarea_focused_inited = true;

    lv_style_init(&st_textarea_focused);
    lv_style_set_border_width(&st_textarea_focused, 3);
    lv_style_set_border_color(&st_textarea_focused, lv_color_hex(0x007ACC));
    lv_style_set_bg_color(&st_textarea_focused, lv_color_hex(0xF7FBFF));
}

float ta_to_float(lv_obj_t* ta, float fallback)
{
    if (!ta) return fallback;
    const char* txt = lv_textarea_get_text(ta);
    if (!txt || txt[0] == '\0') return fallback;
    return atof(txt);
}
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

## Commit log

2026-09-24 Update master thesis repository
    [Aluminum profile_160mm.ipt, Aluminum profile_230mm.ipt, Aluminum profile_70mm.ipt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]
2026-10-06 Revise README for clarity on syringe pump project
    Updated the overview and key results sections to enhance clarity and detail about the viscosity-controlled syringe pump's development and validation.
